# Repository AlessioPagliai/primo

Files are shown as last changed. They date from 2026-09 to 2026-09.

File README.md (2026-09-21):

# primo 

Open source humanoid robot. 3D printed structure, 30 RobStride quasi-direct-drive actuators, NVIDIA Jetson AGX Thor, Unitree G1 kinematics as reference. Still in design, not built yet: shared now so it can be built together.

[CAD on Onshape](https://cad.onshape.com/documents/2a6d830c153f862229ff478f/w/82c50406ffe66995476ba0a1/e/6ac57dbaf03b523effa40409) · [BOM](bom/bom.xlsx) · [Electrical scheme](electrical/scheme.md) · [Printable STL](cad/stl/) · [URDF](sim/urdf/primo.urdf) · [Simulation](sim/) · [Design notes](docs/) · [River Family](https://riverfamily.art/)

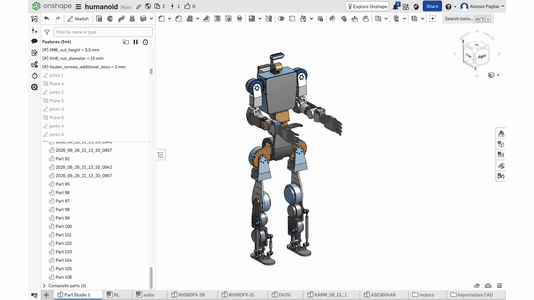
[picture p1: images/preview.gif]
primo, CAD tour and walking in Isaac Lab (https://youtu.be/6nTcHpFmKbQ)


[▶ Video in 4K](https://youtu.be/6nTcHpFmKbQ) · [Download the whole folder](https://storage.googleapis.com/riverfamily/primo/primo.zip) · [Start here to continue the project, also with an AI](AGENTS.md)

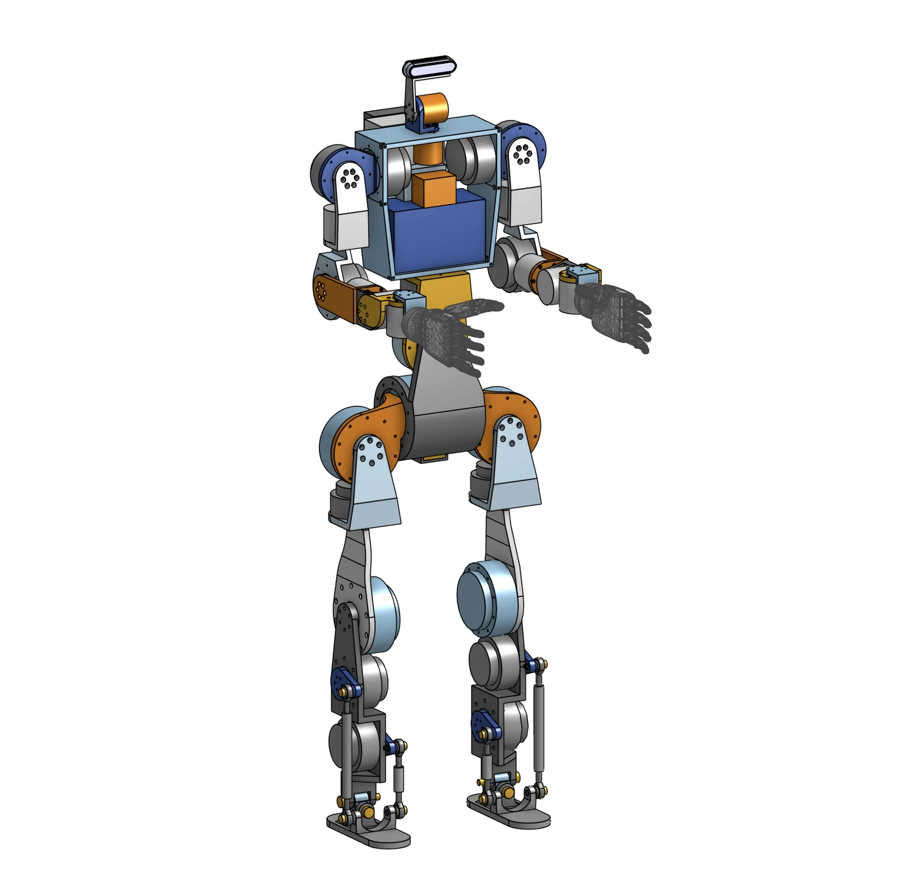
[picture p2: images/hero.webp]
primo


## Numbers

- height ≈ 1.40 m, purchased mass 33 kg, finished estimate ≈ 45 kg
- 30 DoF: legs 6 + 6, arms 7 + 7, waist 2, neck 2
- ankle: two motors in the shin, two pushrods, offset gimbal — pitch is the sum, roll the difference
- actuators, all RobStride QDD: RS04 ×6 hips and knees, RS03 ×3 waist roll and hip yaw¹, RS06 ×11 ankles, waist yaw, shoulders, elbows, RS00 ×8 shoulder yaw and wrists, RS05 ×2 neck
- power: 48 V 13S2P Li-ion 421 Wh, 24 V rail for computer and hands, hardware e-stop with precharge
- compute: Jetson AGX Thor, 5 CAN buses at 1 Mbps, RealSense D436, pelvis IMU
- hands: Inspire RH56DFX, an own 15-DoF hand is in development ([docs/hand-design.md](docs/hand-design.md))
- structure: PA-CF / PPA-CF, Bambu Lab H2C, 0.4 nozzle
- cost: ≈ EUR 30 000 all new; ≈ EUR 10 300 if Thor and hands are already owned

¹ hip yaw: the CAD currently mounts RS06, the BOM RS03. Decided by simulation before ordering the legs.

## Build order

| Phase | Content | EUR incl. VAT |
|---|---|---:|
| 1 | right arm, right hand, one ankle kit, battery, safety chain, torso on a table | 4 009 |
| 2 | legs and locomotion | 3 998 |
| 3 | left arm, waist, neck, audio, mobile | 2 258 |

Filter the `Phase` column in [bom/bom.xlsx](bom/bom.xlsx). Every row has supplier, link, mass and notes. Thor and hands are counted at zero because they are owned; reference prices are in the notes.

## Files

| Folder | Content |
|---|---|
| [bom/](bom/) | `bom.xlsx` 108 active rows, `bom.csv`, `build_bom.py` generator |
| [electrical/](electrical/) | connection scheme, written and drawn |
| [cad/](cad/) | Onshape link, printable STL of the structure, first 3MF files, RobStride FeatureScript |
| [cad/bonegen/](cad/bonegen/) | generated bones: a bone is grown by topology optimisation between the screw holes of two motors, clear of everything that moves. Thigh pilot, plan for the whole robot |
| [sim/](sim/) | URDF with meshes, mirror pipeline, ankle transmission map |
| [sim/isaaclab/](sim/isaaclab/) | walking: trained policy, Isaac Lab task code, how it was reached round by round, traps, results, next steps |
| [docs/](docs/) | why RobStride and not Encos or CubeMars, actuator tables, hand design, references, AI handoffs and working memory |
| [AGENTS.md](AGENTS.md) | entry point to continue the project, for people and AI agents |

What is printed is in `cad/stl/`. What is bought — motors, hands, battery, computer, camera, pushrods, screws — is in the BOM.

## Simulation

The right side and the centre are modelled in Onshape; `sim/mirror_urdf.py` mirrors them into the full 30-joint URDF with masses, limits and collisions: [sim/urdf/primo.urdf](sim/urdf/primo.urdf).

Walking is trained in Isaac Sim 5.1 / Isaac Lab 2.3.2 with RSL-RL PPO, on rough terrain with stairs of 5–23 cm: 12 leg joints + waist roll, mean knee flexion 36°, about 87 % of a 1000-step episode survived. Everything is in [sim/isaaclab/](sim/isaaclab/): the policy `kneehard_model_2999.pt` with the exact parameters it was trained with, the task code, the diagnostic scripts, the [story round by round](sim/isaaclab/HANDOFF.md), the [traps](sim/isaaclab/LESSONS.md), the [measured results](sim/isaaclab/RESULTS.md) and the [next steps](sim/isaaclab/NEXT_STEPS.md).

It is at 2:06 of the [video](https://youtu.be/6nTcHpFmKbQ). Clips: [KneeHard, the chosen policy](https://storage.googleapis.com/riverfamily/primo/videos/walk-kneehard.mp4) · [KneeTorque](https://storage.googleapis.com/riverfamily/primo/videos/walk-kneetorque.mp4).

## Motors

All RobStride, after comparing Encos (the motors of the Asimov robot), CubeMars, Steadywin, MyActuator, ZeroErr and Dynamixel. Encos is smaller and lighter at the same torque, but its 25–36:1 reduction gives up backdrivability and force control for good, worst on the ankle, and it is sold on quotation without public CAD. The comparison and the reasons: [docs/motor-selection.md](docs/motor-selection.md), every number in [docs/actuator-tables.md](docs/actuator-tables.md). Standard modules against custom actuators whose housing is the bone, and how a later version could get there: [docs/actuator-integration.md](docs/actuator-integration.md).

## Open points

- nothing built yet: phase 1 is the first bench
- before ordering: battery shipping to Italy and BMS limits, real ankle crank geometry, hip yaw motor — measure its torque while turning in simulation, RS06 36 Nm or RS03 60 Nm ([how](sim/isaaclab/NEXT_STEPS.md))
- walking policy: no pushes, no domain randomisation and arms held still so far; not yet ready for the real robot
- ankle torque map is derived from the CAD export and still to be verified
- e-stop does not cut hand power: decide whether it should
- STL are exported from the design state, not print-validated
- the CAD femur touches the shank assembly from about 123° of knee flexion (URDF limit 165°): decide the real joint limits ([cad/bonegen/](cad/bonegen/))
- generated bones are a pilot with assumed loads: next, loads logged from the walking policy and 2 mm resolution

## Also on

[Printables](https://www.printables.com/model/1846831) · [Thingiverse](https://www.thingiverse.com/thing:7411626) · [Cults](https://cults3d.com/en/3d-model/gadget/primo-open-source-humanoid) · [MakerOnline](https://www.makeronline.com/en/model/primo%20open%20source%20humanoid/331171.html) · [YouTube](https://youtu.be/6nTcHpFmKbQ) · [riverfamily.art](https://riverfamily.art/#primo)

## Licence

[CC0 1.0](LICENSE.md). One exception: the task code in `sim/isaaclab/code/` derives from Isaac Lab and keeps its [BSD-3-Clause licence](sim/isaaclab/code/LICENSE). Vendor files are not redistributed as CAD: motor and hand STEP files, manuals and the Unitree URDF are linked from [docs/references.md](docs/references.md).

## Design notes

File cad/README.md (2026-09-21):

# CAD

Generated bones (topology optimisation between the motors' screw holes): [bonegen/](bonegen/).

Onshape, public document: [primo](https://cad.onshape.com/documents/2a6d830c153f862229ff478f/w/82c50406ffe66995476ba0a1/e/6ac57dbaf03b523effa40409) (in Onshape it is still titled "humanoid")

Only the right side and the centre are modelled. Onshape assembly mirror does not work for real components (a mirrored motor does not exist), so the left side is generated in the simulation pipeline; in CAD, reuse the same parts and mate them to the mirrored skeleton points. Joint positions come from the Unitree G1 `g1_29dof_mode_11` URDF ([sim/g1_joints_reference.csv](../sim/g1_joints_reference.csv)).

Motors are imported STEP files from the manufacturer (not included here, see [docs/references.md](../docs/references.md)). `motor_proxy.fs` is a FeatureScript that draws RobStride envelope proxies with bolt patterns.

## STL

`stl/` — the printed structure: 20 parts, 35 files, millimetres, left and right where the part is mirrored. Exported from the current CAD through the URDF pipeline, in link coordinates: orient them in the slicer. Design state, not print-validated. For STEP or a finer tessellation export from the Onshape document.

| Area | Parts |
|---|---|
| leg | `hip_pitch_to_roll`, `hip_roll_to_yaw`, `femur`, `tibia`, `ankle_crank_upper`, `ankle_crank_lower`, `ankle_gimbal`, `foot` |
| torso | `pelvis`, `waist_roll_to_yaw`, `ribcage`, `neck_yaw_to_pitch`, `head` |
| arm | `shoulder_pitch_to_roll`, `shoulder_roll_to_yaw`, `elbow`, `elbow_pitch_to_forearm_roll`, `forearm_roll_to_pitch`, `forearm_pitch_to_yaw`, `wrist` |

Bought, not printed: motors, hands, battery, computer, camera, converters, pushrods, rod ends, screws. They are in the [BOM](../bom/bom.xlsx); their meshes exist only in [sim/meshes](../sim/meshes/) for the simulation.

## 3MF

First printed parts, Bambu Studio projects, settings inside the files.

| File | Part | Print |
|---|---|---|
| [ankle-gimbal.3mf](3mf/ankle-gimbal.3mf) | foot–shin offset gimbal, two Ø8 shoulder-screw axes stacked in Z, pitch above roll | Bambu PPA-CF, H2C, 0.4 nozzle, 0.2 mm, 1 wall, 90 % grid infill |
| [leg-test-plate.3mf](3mf/leg-test-plate.3mf) | femur, hip roll-to-yaw bracket, tibia — fit test | PLA, H2S, 0.4 nozzle, 60 % infill |

More parts follow as the design is frozen.

## Ankle

Two RS06 in the shin, one 47 mm crank each, two pushrods with igus rod ends onto the foot. Both motors move both axes: pitch = sum, roll = difference. Pins: shoulder screws Ø8 × M6, 45 mm for the gimbal axes, 16 mm for the rod-end pivots.

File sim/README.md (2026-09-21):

# Simulation

## URDF

`urdf/primo.urdf` — 30 joints, masses, limits, RobStride torque limits, first collision bodies, 32 kg. `meshes/` — 233 STL in metres, every part including the bought ones, used by the URDF. Import into Isaac Sim with *merge fixed joints* on, floating base, self-collision off.

To rebuild it after a CAD change: export the right side + centre from Onshape (URDF exporter, `rl/urdf/rl.urdf` + `rl/meshes/`), then

```bash
python3 mirror_urdf.py ~/Downloads/rl ~/Downloads/rl_full
```

The script identifies the 17 exported joints by position, renames them (`right_hip_pitch_joint` …), converts them to revolute with limits and torque limits, mirrors leg and arm into the left side, bakes mirrored STL meshes (`*_mirror.stl`), injects the real masses (motors, battery, Thor, electronics are recognised by name) and adds collision bodies. Verified symmetric to 0.000 mm. The raw export used for the current URDF is in `onshape_export/rl.urdf`; its meshes are the files in `meshes/` without `_mirror`. What is verified and what is provisional: [docs/handoffs/mirror-debug.md](../docs/handoffs/mirror-debug.md).

## Ankle transmission

`ankle_map.py` — exact inverse/forward kinematics of the pushrod differential, Jacobian, coupled torque envelope. The simulator uses two virtual joints (pitch, roll); this map converts them to the two motor angles at deploy time. Geometry constants are provisional, see [ankle-transmission.md](ankle-transmission.md).

## Isaac Lab

[isaaclab/](isaaclab/) is the whole locomotion work: the trained policy `policy/kneehard_model_2999.pt` with the parameters it was trained with, the Isaac Lab task package (rewards, terminations, action spaces, every recipe tried), the RobStride articulation with gains and limits, left-right symmetry augmentation for a biped, the diagnostic scripts, and the written record — `HANDOFF.md` round by round, `LESSONS.md` symptom → cause → fix, `RESULTS.md`, `NEXT_STEPS.md`, `setup/INSTALL.md` with the version pins. Start from [isaaclab/README.md](isaaclab/README.md): it also says which paths to edit and how `rl_full.urdf` maps to `urdf/primo.urdf`.

Earlier notes for the import, gains and acceptance tests: [docs/handoffs/isaac.md](../docs/handoffs/isaac.md). Legs run the RL policy; arms, hands and neck are teleoperated ([docs/handoffs/teleop.md](../docs/handoffs/teleop.md)).

Walking on rough terrain: [video at 2:06](https://youtu.be/6nTcHpFmKbQ) · [walk-kneehard.mp4](https://storage.googleapis.com/riverfamily/primo/videos/walk-kneehard.mp4) · [walk-kneetorque.mp4](https://storage.googleapis.com/riverfamily/primo/videos/walk-kneetorque.mp4)

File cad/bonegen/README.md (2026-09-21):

# bonegen — generated bones for primo

Handoff for the AI session on the simulation workstation. Goal set by the user: **all the bones of the robot generated, and the robot walking in Isaac Lab with them**, with the loads taken from the simulation, not assumed.

Idea: the motors stay where the CAD puts them. A bone is whatever connects the screw holes of two motors without touching anything that moves. It is generated by topology optimisation from: the motors, their screw holes, the volumes swept by the neighbours over the joint range, the screw head and tool paths, and the loads. Change a motor → change one entry → regenerate.

Mounting is the standard one for every motor (user decision): **one bone on the body holes (outer), the other bone on the output holes (inner), both on the output face.** No back mounting.

## Files

| File | What it is |
|---|---|
| `bonegen.py` | the pipeline, one file: voxelise → pads / keep-outs / screw paths → SIMP optimisation with several load cases → smooth mesh of the same volume → exact pads, holes, counterbores and motors cut with booleans → `report.json` |
| `thigh_free.json` | pilot, **free mode**: no CAD bone as input, only motors + holes + keep-outs + loads |
| `thigh.json` | same bone in CAD-interface mode (copies the attachment zones from the CAD femur). Used only to measure the current femur as baseline. Not the way forward: the copied zones ate 97 of the 187 cm³ |
| `render.py` | small renderer for comparison pictures, no GPU needed |
| `results/` | the 4 mm pilot: generated thigh (`final.stl`, millimetres, robot root frame), `report.json`, `thigh_compare.png` |

Meshes: the configs read the robot STL (metres, root frame, zero pose) from `sim/meshes` of the repository (`mesh_dir`). Known defect of the pilot mesh: a few needle-like sliver triangles from the smoothing; clean them before printing.

Setup: `python -m venv .venv`, `pip install numpy scipy pyamg scikit-image trimesh manifold3d`.
Run: `python bonegen.py thigh_free.json --pitch 4 --iters 70`; `--remesh` redoes check and meshes from a saved density; `--find-holes motor.stl y@-120:-112` lists the round holes of a mesh inside a slab.

## Config in short

- `envelope_mm` box where material may exist; `volume_cm3` mass budget (187.2 = current femur, solid PA-CF as the URDF assumes).
- `interfaces` of type `pads`: `axis`, `face` (coordinate of the motor's mounting face), `side` (which way the bone grows), `holes` (centres in the two other axes), `pad_d`, `pad_t`, `hole_d`, `head_d`, `head_depth` (counterbore), `access_len` (straight tool path kept empty), optional `ring` joining the pads. Pads are solid, holes / counterbores / tool paths are empty, both exact in the final mesh.
- `keepout_static` bodies that move with the bone. `sweeps` bodies that turn past it: swept over `range` (or `use_range`) in 3° steps, grown by `clearance_mm`. The report says if a pad lies inside a swept volume (`interface_inside_swept_volume_mm3`).
- `load_cases` wrenches at `load_centre` spread on the load pads; the other interface is fixed. Objective = sum of compliance / compliance of the current bone, so every case counts the same.

## Motor screw patterns found so far (from the meshes — check against the RobStride drawings)

| Motor | Pattern | Found |
|---|---|---|
| RS06 | output (rotor) | 6 × M4 on Ø24, on the output face |
| RS04 | body | 10 × Ø4 on Ø106.6, through the lobes; mounting face 3.6 mm behind the rotor face |
| RS04 | output (rotor) | 6 × Ø5 on Ø36 |

To do: the same for RS00, RS03, RS05 and the body pattern of RS06, in one `motors.json`, so that a bone config only says "output of motor A, body of motor B".

## What the pilot showed (Mac, 4 mm, ASSUMED loads — indicative only)

- The current CAD femur is a flat 10 mm plate. The knee of the CAD: femur plate y −129.4…−139.4 on the body holes, shank plate from −141.5 on a Ø50 hub through the femur ring. Gap 2.1 mm: **screw heads of the femur must be counterbored** or they hit the shank. Done in `thigh_free.json` (M4, 4.5 mm deep).
- Range of motion: **the current CAD femur touches the shank assembly from about 123° of knee flexion**; the URDF limit is 165° (inherited from the reference robot). The pilot keeps 0–120° free. The walking policy uses −5…116°. The real limits must be decided joint by joint.
- Free mode, same mass, forces on the leg line (y = −127), stiffness of the generated thigh against the CAD femur: lateral bending ×1.75, torsion ×1.47, knee-motor torque ×0.92, fore-aft ×0.95, axial ×0.59 (in absolute terms 0.14 → 0.24 mm under twice the body weight). In words: the flat plate is already efficient in its own plane and weak sideways and in twist; the generated shape trades a little of the first for a lot of the second. Overall a draw at this resolution. Picture: `thigh_compare.png` (current left, generated right; neighbours in blue, motors in grey, bone seen from above on the right of each group).
- At 4 mm the surface is lumpy and thin members are unreliable. Real results need 2 mm.

## Plan for the full robot

1. **Loads from the simulation.** Play the walking policy (`Isaac-Velocity-R5-KneeHard-Play-v0`; `knee_probe.py` shows how to patch `play.py`). For every joint log per step the 6D wrench the joint transmits (`robot.root_physx_view.get_link_incoming_joint_force()`, check frame and sign once with a static pose where the answer is known: robot hanging, then standing) and `robot.data.applied_torque`. Include turning, stairs, stops, and a few pushes. Per bone build 6–10 load cases: the step where each force and moment component peaks (use the 99.5th percentile, contact spikes are partly solver artefacts), plus a fall/impact case and the static worst cases. Confidence: good for walking loads, poor for impacts — keep a safety factor and say so.
2. **Bones to generate** (printed parts that are pure connections): hip pitch→roll bracket, hip roll→yaw bracket, femur, tibia (two ankle motors and pushrods inside: many keep-outs), upper arm, forearm, shoulder brackets. Keep from CAD for now: pelvis, torso, foot, ankle gimbal and cranks.
3. **Neighbours.** A bone's keep-out is the swept volume of its neighbours. Round 1 uses the CAD neighbours. Round 2 regenerates each bone against the generated neighbours. Then a clash check of every pair over the joint ranges (same `swept()` lookup) before anything goes to the simulator.
4. **Resolution.** 2–2.5 mm. CPU (scipy + pyamg) works but takes hours per bone. Faster: replace `Grid.solve` by a matrix-free conjugate gradient on the GPU (PyTorch float64: gather `u[edof]`, multiply by `KE * E_e`, `index_add_` back, Jacobi preconditioner, warm start). Nothing else changes.
5. **Back into Isaac Lab.** Mass, centre of mass and inertia of each generated bone (trimesh, density 1.25 g/cm³) → into the URDF in place of the CAD values, generated STL as visual meshes (left side by mirroring) → `convert_urdf.py --merge-joints` → fine-tune KneeHard → record the video → log the loads again → one more round of bones if they changed much. Isaac Lab cannot optimise bones while walking (links are rigid, there is no stress inside them): the loop runs in rounds.
6. **Then lighter.** Once stiffness is matched with real loads, run `--vol 0.8` and `0.7`.
7. **Printing.** FDM PA-CF is weak between layers: minimum member ≥ 5 mm, print orientation with the main load paths in the layers, or MJF/SLS for these parts. Material data from printed coupons before any safety factor is claimed.

## Rules

Never present an assumed load or modulus as measured. Interfaces exactly as the motors require. English only, assistants are called "AI".

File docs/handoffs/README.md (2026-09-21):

# AI handoffs

The design is developed together with AI agents. These files let an agent — or a person — continue the work without redoing it. Entry point: [AGENTS.md](../../AGENTS.md).

- [ai-memory.md](ai-memory.md) — the raw working memory, source of truth for every decision, with dates, sources and open doubts. Newest blocks are at the top; older sections below are marked when superseded. Read this first.
- [isaac.md](isaac.md) — importing the URDF into Isaac Sim / Isaac Lab, gains, acceptance tests, hip-yaw motor gate.
- [../../sim/isaaclab/](../../sim/isaaclab/) — the locomotion training handoff, kept with its code and policy: `HANDOFF.md` (the journey round by round), `LESSONS.md` (traps), `RESULTS.md`, `NEXT_STEPS.md`, and in `reference/` the raw work log of the simulation workstation.
- [teleop.md](teleop.md) — Meta Quest teleoperation of arms and hands, legs on the RL policy.
- [mirror-debug.md](mirror-debug.md) — what is verified in the URDF mirror pipeline and what is provisional.
- [../motor-selection.md](../motor-selection.md) — why RobStride: the comparison with Encos (Asimov), CubeMars and the others, distilled from the memory.

Rule kept throughout: no hypothesis becomes a BOM row; unknown dimensions stay `qty 0` with the missing data listed.

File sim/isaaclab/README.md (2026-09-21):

# Humanoid Locomotion — RL Training Handoff

Reinforcement-learning locomotion for an open-hardware 30-DOF humanoid (all-RobStride QDD
actuators, Unitree G1 as the geometric reference), trained in **NVIDIA Isaac Sim 5.1 / Isaac Lab
2.3.2** with **RSL-RL PPO**.

This folder contains the trained walking policy, every config needed to reproduce it, the
diagnostic tooling built along the way, and — most importantly — **a written record of what went
wrong and why**, so the next person does not repeat five rounds of mistakes.

## In this repository

The robot is called **primo**. This folder is the training package as it left the simulation workstation. Added here: this section and `code/LICENSE`; in `reference/` the assistants are called "AI".

- **URDF** — `rl_full.urdf` in these documents is [sim/urdf/primo.urdf](../urdf/primo.urdf), meshes in [sim/meshes/](../meshes/). Same export, robot name changed to `primo`. Checked: the foot mesh here has the extents the foot-collision script expects (sole at z = −0.7883 m, centre x 0.0333, y ∓0.1267).
- **USD** — not included, it is built from the URDF: foot-collision fix, then `convert_urdf.py --merge-joints` ([setup/INSTALL.md](setup/INSTALL.md)). `primo.urdf` still has the mesh collision on the feet, so run `simplify_foot_collision.py` on a copy first.
- **Paths** — written on a Windows workstation, the files point to `C:\Users\WKS\...`. Edit before running:

| File | What to change |
|---|---|
| `code/assets/robstride.py` | `ROBSTRIDE_USD_PATH` → your converted USD |
| `code/assets/project_humanoid.py` | asset folder |
| `code/scripts/simplify_foot_collision.py`, `audit_collisions.py`, `foot_zero_check.py`, `solve_elbow_angle.py` | `URDF` (and `MESHES`) → `sim/urdf/primo.urdf`, `sim/meshes/` |
| `code/scripts/preview_pose.py`, `joint_jog.py` | `USD_PATH`, `OUT_DIR` |
| `code/scripts/knee_probe.py` | `PLAY` and the `sys.path` line → your Isaac Lab checkout |
| `code/scripts/*.ps1` | venv, Isaac Lab and log folders |

`policy/params_as_trained/env.yaml` keeps the original paths on purpose: it is the record of the run.

- **Policy input and output** — read from the checkpoint and from `env.yaml`:
  - observation 272 = base linear velocity 3 · base angular velocity 3 · projected gravity 3 · velocity command 3 · joint positions relative to default 30 · joint velocities 30 · last action 13 · height scan 187 (1.6 × 1.0 m grid, 0.1 m)
  - action 13 = hip yaw, roll, pitch, knee, ankle pitch, ankle roll ×2 + waist roll. Joint position targets = default pose + 0.5 × action
  - 50 Hz control (physics 0.005 s × decimation 4), actor MLP 512-256-128 ELU, no observation normalisation
  - commands trained: forward 0–1.0 m/s, no lateral, yaw ±1.0 rad/s through a heading command
  - the joint order is the one Isaac Lab resolves from the articulation (`preserve_order: false`), not the order of the list above: read it from the running environment before any deploy
  - the ankle outputs are the two virtual joints (pitch, roll): on the robot they go through [sim/ankle_map.py](../ankle_map.py) to the two motors
- **Licence** — `code/assets/`, `code/symmetry/` and `code/tasks/` derive from Isaac Lab and keep its BSD-3-Clause licence ([code/LICENSE](code/LICENSE)). Everything else, scripts, documents and the policy, is CC0 like the rest of the repository.
- **Where it continues** — open items in [NEXT_STEPS.md](NEXT_STEPS.md). The first one, the hip-yaw torque gate, decides RS03 or RS06 on hip yaw and blocks the leg order.

## What is here

| Path | What it is |
|---|---|
| `policy/` | The chosen policy (`kneehard_model_2999.pt`), a video of it walking, and the exact env/agent YAML it trained with |
| `code/tasks/` | Isaac Lab task definitions: rewards, terminations, action spaces, every recipe tried |
| `code/assets/` | Robot articulation config — PD gains, effort/velocity limits from the real RobStride motors |
| `code/symmetry/` | Left-right symmetry augmentation for a biped (Isaac Lab ships this only for quadrupeds) |
| `code/scripts/` | Diagnostic tools: knee probe, collision audit, pose preview, symmetry verifier, launchers |
| `setup/INSTALL.md` | Environment, exact versions, the two version pins that are not optional, run command |
| `HANDOFF.md` | **The full story** — the journey round by round, what failed and why |
| `LESSONS.md` | **The traps** — distilled, each with symptom → cause → fix |
| `RESULTS.md` | Measured numbers for every experiment |
| `NEXT_STEPS.md` | What to do next (push robustness, unlocking joints, the motor gate) with the traps mapped |
| `reference/` | Raw project memory and the URDF-side handoff, kept as written |

## The policy

`policy/kneehard_model_2999.pt` — 3000 PPO iterations, rough terrain with stairs.

- Action space: 12 leg joints + waist roll (13 DOF). Arms/wrists/neck are PD-held.
- Measured gait: mean knee flexion **36.1°**, range −5°…116°, nearly-straight only **0.4 %** of the time.
- Survives ~87 % of a 1000-step episode on generated rough terrain including 5–23 cm stairs.
- Left-right symmetric (symmetry augmentation active during training).

## Reproduce

See `setup/INSTALL.md`, then:

```bash
# train
isaaclab.bat -p scripts/reinforcement_learning/rsl_rl/train.py \
    --task Isaac-Velocity-R5-KneeHard-v0 --num_envs 1024 --headless

# watch a trained policy
isaaclab.bat -p scripts/reinforcement_learning/rsl_rl/play.py \
    --task Isaac-Velocity-R5-KneeHard-Play-v0 --num_envs 4 \
    --checkpoint /abs/path/to/kneehard_model_2999.pt

# measure whether the knees actually bend (don't trust your eyes)
isaaclab.bat -p code/scripts/knee_probe.py \
    --task Isaac-Velocity-R5-KneeHard-Play-v0 --checkpoint /abs/path/model.pt --headless
```

## Status and next steps

Working: stable symmetric walking on rough terrain and stairs, bent knees, soft landings,
arms held along the body.

Not yet done:
1. **Hip-yaw torque gate** — log applied torque on `*_hip_yaw_joint` during turning. If it
   saturates the 36 Nm RS06 limit for >2–5 % of steps, the BOM's RS03 (60 Nm) is required.
   **This measurement blocks the Phase-1 motor purchase.**
2. Push/disturbance robustness (no push randomisation has ever been enabled).
3. Unlocking more joints (arm swing, waist yaw) for a more natural gait.
4. Domain randomisation (mass, friction, latency) before any sim-to-real attempt.
5. A separate conservative "walk mode" for precise positioning — see `HANDOFF.md` round 3 for
   how *not* to do it.

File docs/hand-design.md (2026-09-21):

# Custom Humanoid Hand Design

Shared engineering handoff for the user and the AI sessions.

Last updated: 2026-07-29

## Project Status

The humanoid will initially use the commercial Inspire Robots
`RH56DFX-2L` and `RH56DFX-2R` hands already represented in CAD and the BOM.
They remain the first-build baseline.

In parallel, the project will develop and open-source its own five-finger
hand. This is a planned project workstream, not merely a component comparison.
The custom hand is intended to replace the Inspire hands after validation.

Do not remove the Inspire hands from the active BOM until the custom hand has
passed force, backlash, heating, impact, lifetime, communication, and
integration tests.

## Intended Kinematics

Target: 15 independently actuated DoF per hand, three per digit.

| Digit | DoF 1 | DoF 2 | DoF 3 |
|---|---|---|---|
| Index, middle, ring, little | MCP abduction/adduction | MCP flexion/extension | PIP flexion/extension |
| Thumb | CMC opposition/reposition | CMC or MCP flexion/extension | IP flexion/extension |

The thumb must not blindly copy the four-finger axis arrangement. Opposition
is required for useful pinch grasps.

The DIP joints can initially be mechanically coupled to their corresponding
PIP joints or left passive. This preserves three controlled DoF per digit
without adding a fourth actuator.

The preferred architecture places an actuator physically at each controlled
joint. Tendon actuation remains the fallback if no sufficiently compact,
controllable, and reproducible commercial actuator is available.

## Packaging Reality

The DYNAMIXEL X330 envelope is `20 x 34 x 26 mm`. Although compact for a smart
servo, it is large for a human-scale PIP joint:

- A bare 20 mm motor thickness becomes approximately 24-28 mm after adding
  structural cheeks and an opposite-side support.
- The 34 mm body consumes most of a phalanx length.
- Adjacent fingers can collide during abduction.
- A motor mounted at the PIP increases distal inertia.
- Connectors and moving cable loops require additional clearance.

Therefore, XL330/XC330 actuators are suitable in a palm or forearm and possibly
at selected MCP joints, but are poor candidates for every direct PIP joint.

## Actuator Comparison

Torque values must distinguish sustainable/rated operation from momentary
stall torque.

| Actuator | Size | Mass | Rated or conservative torque | Stall or maximum torque | Control and feedback | Status |
|---|---:|---:|---:|---:|---|---|
| Waveshare `SC09` / Feetech `SCS009` | 23.2 x 12.0 x 25.5 mm | 12.5 g | 0.0686 Nm | 0.2256 Nm | TTL bus; position, estimated load, speed, voltage | Leading retail direct-joint prototype candidate |
| DYNAMIXEL `XL330-M288-T` | 20 x 34 x 26 mm | 18 g | about 0.104 Nm | 0.52 Nm | Absolute magnetic encoder, current control, current/temperature feedback, TTL | Technically better, but bulky on fingers |
| DYNAMIXEL `XC330-T288-T` | 20 x 34 x 26 mm | 23 g | about 0.20 Nm | 1.00 Nm | Absolute encoder, current control, metal gears, TTL | Strong and durable but bulky and expensive |
| KST `X06` | 20 x 7 x 16.6 mm | 6 g | 0.040 Nm | 0.176 Nm | PWM; no normal runtime telemetry | Fits easily but weak and poor for state logging |
| AGFRC `A20CLS` | 23 x 12 x 27.5 mm | 20 g | not published | 0.735 Nm advertised at 8.4 V | PWM, potentiometer, no normal runtime current telemetry | Compact and strong, but weak research interface |
| Harmonic Drive `RSF-3C` | approximately diameter 20 x 47 mm | 31 g | 0.03-0.11 Nm | 0.13-0.30 Nm, ratio-dependent | Incremental encoder; external servo driver required | Robot-grade but long, expensive, quotation-oriented |
| Bonsystems `BCSA Micro` | diameter 18 mm; other dimensions unpublished | unpublished | unpublished | unpublished | Unpublished | Promising dedicated finger actuator, not BOM-ready |

### Product Links

- SC09 product and CAD: <https://www.waveshare.com/SC09-Servo.htm>
- SC09 documentation: <https://www.waveshare.com/wiki/SC09_Servo>
- XL330-M288-T European supplier:
  <https://www.generationrobots.com/it/403817-servomotore-dynamixel-xl330-m288-t.html>
- XL330 official manual and CAD:
  <https://emanual.robotis.com/docs/en/dxl/x/xl330-m288/>
- XC330-T288-T European supplier:
  <https://www.generationrobots.com/it/403891-servomotore-dynamixel-xc330-t288-t.html>
- XC330 official documentation:
  <https://emanual.robotis.com/docs/en/dxl/x/xc330-m288/>
- KST X06 European supplier:
  <https://openelab.io/it/products/kst-x06-v6-hv-servo>
- AGFRC A20CLS manufacturer:
  <https://www.agfrc.com/index.php?id=2429>
- AGFRC A20CLS European supplier:
  <https://www.monsterhopups.de/Servo-AGF-RC-A20CLS>
- Harmonic Drive RSF-Supermini:
  <https://staging.harmonicdrive.net/products/actuators-and-motors/solid-shaft-actuators/rsf-supermini>
- Bonsystems BCSA Micro:
  <https://en.bonsystems.com/media-center/product-video/micro-actuator-bcsa-micro-series-promotion-viedo/>

## SC09 Versus XL330 Torque

The XL330 is not merely a more expensive SC09. It is stronger and provides
substantially better sensing and control:

- Conservative normal torque ratio:
  `0.104 / 0.0686 = 1.52`.
- Stall torque ratio:
  `0.52 / 0.2256 = 2.30`.
- XL330 encoder resolution: 4096 positions over 360 degrees, 0.088 degrees.
- SC09 sensor resolution: 1024 positions over 300 degrees, 0.293 degrees.
- XL330 supports measured-current control and current-limited position control.
- SC09 reports an estimated load value, not calibrated joint torque.

The SC09 advantage is packaging and cost:

- Thickness: 12 mm instead of 20 mm.
- Bounding volume: approximately 7.1 cubic centimetres instead of 17.7.
- Mass: 12.5 g instead of 18 g.
- Retail price: approximately USD 8.99 instead of about EUR 40.20.

## Approximate Fingertip Force

First-order estimate:

`fingertip force = joint torque / distance from joint to contact`

This ignores changing contact geometry, transmission losses, compliance, and
multi-joint load sharing.

| Joint and assumed lever | SC09 rated | SC09 stall | XL330 conservative | XL330 stall |
|---|---:|---:|---:|---:|
| MCP, 70 mm | 0.98 N | 3.22 N | 1.49 N | 7.43 N |
| PIP, 30 mm | 2.29 N | 7.52 N | 3.47 N | 17.33 N |

Stall force is momentary. It must never be used as sustainable grasp force.

The SC09 is dimensionally plausible for a direct-joint hand, but its
approximately 1 N rated MCP fingertip force makes it a light-manipulation
candidate. A complete grasp is also limited by the thumb opposition joint and
the available fingertip friction.

## Complete-Hand Implications

### Fifteen SC09 Actuators

- Actuator mass: approximately 187.5 g per hand.
- Motor purchase cost: approximately USD 135 per hand before shipping/tax.
- Theoretical simultaneous stall current: 15 A at 6 V.
- One shared TTL bus is possible, with adequate parallel power distribution.
- Suitable for a compact first prototype and light manipulation.
- Not yet proven adequate for useful box lifting or tool operation.

### Fifteen XL330 Actuators

- Actuator mass: 270 g per hand.
- Motor purchase cost: approximately EUR 603 per hand.
- Theoretical simultaneous stall current: about 22.1 A at 5 V.
- Better torque, state feedback, current limiting, SDK, and ROS support.
- Poor direct-PIP packaging.
- Better suited to protected palm/forearm tendon actuation.

### Mixed XL330 and SC09

A possible architecture would use XL330 motors at MCP flexion and SC09 motors
at MCP abduction and PIP flexion. This improves proximal torque while keeping
the fingers thinner.

However:

- The two products use different serial protocols.
- They require separate UART/protocol handling even if both use a common
  approximately 5 V power rail.
- The mechanical and control behaviour would be inconsistent across joints.

This remains an option, not a selected design.

## Mechanical Requirements

Every direct rotary joint should include:

- A motor-driven side and a coaxial passive support on the opposite side.
- A fork or double-shear structure rather than a long cantilever from the
  servo horn.
- Mechanical end stops before software or internal servo limits.
- Replaceable joint modules and accessible fasteners.
- Cable strain relief and a controlled flex loop at each moving joint.
- Finger pads with known friction and some passive compliance.
- Clearance for adjacent fingers throughout abduction and full flexion.
- A protected cable route that cannot enter pinch points.

The final CAD should model the complete actuator, horn, opposite support,
fasteners, connectors, cable bend radius, and service clearance. Comparing
only bare motor bodies is insufficient.

## Sensing And Learning Requirements

For teleoperation, ACT policies, and simulation-to-real work, record at least:

- Commanded joint position.
- Measured joint position.
- Joint velocity.
- Motor current or the best available load estimate.
- Bus voltage.
- Temperature when available.
- Command and feedback timestamps.

The SC09 does not provide measured current or temperature. Its load value must
be characterized experimentally and must not be treated as calibrated torque.
External fingertip tactile sensors or force-sensitive resistors may eventually
be required for controlled grasping.

## Validation Plan

Do not purchase 30 custom-hand actuators before validating one finger.

### Prototype 1

Build one index finger with:

- MCP abduction/adduction.
- MCP flexion.
- PIP flexion.
- A passive or coupled DIP.
- The intended structural material, bearings/supports, cables, and fingertip
  pad.

SC09 is the current first actuator to test because it is inexpensive and
dimensionally plausible. This is a test choice, not the final hand lock.

### Measurements

1. Sustained fingertip force for at least 60 seconds.
2. Peak force without using prolonged stall.
3. Loaded position error.
4. Backlash and deadband in both directions.
5. Temperature over repeated grasp cycles.
6. Impact survival with conservative test loads.
7. Wear after repeated cycles.
8. Bus update rate with three nodes, then fifteen nodes.
9. Simultaneous current draw during realistic grasps.
10. Ability to identify joint state accurately enough for teleoperation and
    policy training.

### Selection Gate

Freeze the actuator and hand CAD only after the prototype demonstrates:

- Sufficient sustainable force for the intended objects.
- Acceptable backlash and repeatability.
- No thermal failure in repeated use.
- Adequate impact durability.
- Reliable multi-node communication.
- A realistic power and wiring architecture.

If SC09 fails force or sensing requirements, compare a stronger direct module,
a mixed MCP/PIP design, or a palm-mounted tendon architecture. Do not solve a
failed actuator test by designing around advertised stall torque.

## Current Decision Summary

- Inspire RH56DFX remains the first humanoid hand.
- A custom open-source 15-DoF hand will be developed in parallel.
- Direct joint actuation is preferred.
- XL330/XC330 are too bulky for every human-scale PIP joint.
- SC09 is the leading low-cost direct-joint prototype candidate, but it is
  weaker and less observable than XL330.
- No custom-hand actuator is procurement-locked.
- The immediate next step is one instrumented three-DoF finger prototype.

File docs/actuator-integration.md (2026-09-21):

# Standard motors, or the housing as the bone

primo uses standard actuator modules: a closed cylinder with a bolt circle on the body and a bolt circle on the rotating output face. The best commercial humanoids use custom actuators whose housing is the structural link itself. This page records what that difference costs, what stays valid in the future, and how a later version of the robot could move towards integrated housings. Market statements are general knowledge on 2026-09-21, not a verified survey.

## Two families

| | Standard module (RobStride, CubeMars, Encos, cobot joints) | Custom integrated (Unitree, Tesla, Figure) |
|---|---|---|
| Interface | bolt circle on the body, bolt circle on the output face | the link is the housing, or clamps around it |
| Who can build it | anyone, parts can be ordered | only the maker |
| Torque per mass | RS04 ≈ 84 Nm/kg | Unitree custom ≈ 189 Nm/kg |
| Housing | dead mass, carried inside a bone | structure, heat sink and cable duct at once |
| Robot | primo ≈ 45 kg | G1 ≈ 35 kg |

Both families will keep existing. Robot arms built from standard joint modules bolted to simple links have been an industry for fifteen years; humanoids on standard modules already walk (Asimov on Encos, ToddlerBot on Dynamixel, primo in simulation). The number of module makers grows and prices fall. The penalty of the standard route is mass and bulk at the joints, not the ability to walk. For an open source robot standard modules are the point: a custom housing cannot be rebuilt by others.

## What is future proof and what is not

- Not future proof: bones drawn around the exact shape of one motor.
- Future proof: the motor as a swappable box with a declared interface — axis, envelope, body holes, output holes — and bones regenerated from that description. This is what [cad/bonegen/](../cad/bonegen/) does. A better module (lighter, hollow shaft, clampable) then costs one entry in the motor list and a new run.
- Mounting rule kept for every motor: one bone on the body holes (outer), the other bone on the output holes (inner), both on the output face. The consequence is measured in the CAD knee: the thigh is a ring plate on the 10 body holes, the shank reaches the 6 output holes through a Ø50 hub in the middle of that ring, so the shank stands off by the thickness of the thigh plate (10 mm + 2 mm gap) and the thigh screws must be counterbored.
- Clamping a bone around the motor body, as on the G1, suits aluminium links: clamp and heat sink in one. With printed PA-CF it insulates the motor (rated torque is a thermal limit: RS04 120 Nm peak, 40 Nm rated), creeps under preload, and RobStride housings are not specified for radial clamping. Face screws with metal inserts remain the right joint for a printed robot.

## The integrated route, if a later version takes it

What can be bought is a frameless motor kit: two bare rings, the stator (iron stack with the windings) and the rotor (ring with the magnets). Catalogue items from several makers. Nobody makes the stator or the rotor themselves. Everything else is made or sourced:

- housing: holds the stator by press or bonded fit and is its heat path, so aluminium
- rotor hub, rotor bearings, and an output bearing that carries the joint moments (crossed roller or a thin-section pair)
- gearbox, the hard part. Low reduction: a single-stage planetary in hardened steel from a gear shop. Berkeley Humanoid Lite prints a cycloidal stage in plastic. High reduction: a harmonic component set, three parts made to be built into a custom housing
- two encoders (rotor and output), magnet ring and sensor chip
- driver board with field-oriented control and CAN
- assembly: retaining compound, fits of a few hundredths, a jig to insert the rotor against the pull of the magnets

A complete low-reduction actuator with gearbox, encoders, driver and hollow shaft, sold without housing so that only the housing is printed, is not a catalogue item as far as known. There is a mechanical reason: in a planetary actuator the housing is part of the gearbox, it carries the ring gear and the bearing seats. The closest things are harmonic servo kits made for integration (high reduction and expensive: rejected for the legs in [motor-selection.md](motor-selection.md)), housed modules with a hollow shaft, and asking a module maker for an OEM variant with a custom housing.

Metal printing the housing: services print AlSi10Mg, but as printed it is rough and accurate to about ±0.1–0.2 mm. Stator bore, bearing seats and gear seat are finish-machined afterwards in any case. A plain round housing is cheaper and more precise turned from bar. Printing pays when the housing is also the bone: organic shape printed near net, functional seats machined in one setup.

RobStride and CubeMars are this recipe sold as a product, descended from the MIT Mini Cheetah actuator. At about EUR 200 per actuator it cannot be beaten on cost; the gain would be integration only, against months of development per actuator size, with gear quality and heat as the main risks.

## Suggested path

1. This version on standard modules, bones generated by [cad/bonegen/](../cad/bonegen/).
2. A cheap step available at once: metal bones (machined or printed aluminium) on the hottest joints with the same motors, for stiffness and a real heat path.
3. Later, as a separate experiment on one joint (knee): frameless kit, planetary stage, open driver, on a bench against an RS04 — torque, heat, backlash. Because every bone is generated from a motor interface, the robot can adopt such an actuator joint by joint.

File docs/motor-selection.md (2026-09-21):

# Motor selection

primo uses 30 RobStride quasi-direct-drive actuators. That was decided on 2026-06-20/21, after an all-Encos plan (the route of the Asimov robot) and a CubeMars plan had each been adopted and dropped. This page is the short version. Every number is in [actuator-tables.md](actuator-tables.md); the dated record, with the mistakes, is in [handoffs/ai-memory.md](handoffs/ai-memory.md).

## What was asked of a motor

- low reduction, backdrivable (QDD, 6–10:1): current ≈ torque, stiffness that can be dosed from the controller, tolerance to impacts. It is what Unitree G1 does, and RL walking on it needs no torque sensor
- driver inside, CAN, two encoders (single-encoder versions such as RS01 are excluded, whatever the brand)
- orderable by anyone, with public dimensions and CAD, at a price a university or a maker can pay
- one family from 5 to 120 Nm: one firmware, one debug tool, one set of spares
- compared at equal torque: size and mass first, then cost, then availability

## Timeline

| Date | Step |
|---|---|
| 2026-06-14 | brands compared at equal torque. RobStride is the baseline BOM |
| 2026-06-16 | Asimov v1 taken as reference (same parallel ankle). Its Encos motor map rebuilt joint by joint, Encos quote asked to Foxtech |
| 2026-06-17 | reduction ratio studied for walking: 6–9:1 is the QDD range, reflected inertia grows with the square of the ratio |
| 2026-06-19 | all-Encos list finalised: A6416 ×6 legs, A4315 ×16 mid joints, A2806 ×8 wrists and neck, A4310 ×4 ankle trial |
| 2026-06-20 | reverted: QDD architecture, RobStride supplier, Unitree G1 as the reference. A CubeMars plan made just before is dropped, it rested on wrong dimensions |
| 2026-06-21 | CubeMars AK45-36 (36:1, slim) evaluated for arms and ankles and rejected: all QDD, no high reduction anywhere. Map locked: RS04 ×6, RS03 ×3, RS06 ×11, RS00 ×8, RS05 ×2, 20.9 kg of actuators. Accepted cost: ≈ 45 kg and ≈ 1.40 m instead of 35 kg and 1.20 m |
| 2026-06-23 | RobStride against CubeMars class by class: no switch |

## Asimov and Encos

[Asimov v1](https://github.com/asimovinc/asimov-1) is the closest open robot: 1.2 m, 35 kg, 25 DoF, the same two-motor parallel ankle. It uses Encos actuators on every joint, five models ([their documentation](https://docs.menlo.ai/asimov/1)):

| Encos model | Gearbox | Qty | Joints on Asimov |
|---|---|---:|---|
| EC-A4310-P2-36 | planetary 36:1 | 10 | ankles ×4, elbows ×2, wrist yaw ×2, neck ×2 |
| EC-A4315-P2-36 | planetary 36:1 | 4 | knees ×2, shoulder roll ×2 |
| EC-A6416-P2-25 | planetary 25:1 | 3 | hip pitch ×2, waist yaw |
| EC-A5013-H17-100 | harmonic 100:1 | 4 | hip roll ×2, shoulder pitch ×2 |
| EC-A3814-H14-107 | harmonic 107:1 | 4 | hip yaw ×2, shoulder yaw ×2 |

The map comes from their leg BOM and spreadsheet, the arm joints matched through the `armature` values of their simulation model. Encos is Nanjing Inks Intelligent Technology, resold by Foxtech and AIFITLAB. About USD 7 000 for the 25 actuators.

What Encos does better, and it is not small:

| 36 Nm class | Size | Mass | Nm/kg | Reduction | Price |
|---|---|---:|---:|---|---|
| Encos EC-A4310-P2-36 | Ø56 × 60.5 | 382 g | 94 | 36:1 | ≈ USD 500–700 |
| RobStride RS06 | Ø88 × 49 | 621 g | 58 | 9:1 | ≈ EUR 200 |

On the legs EC-A6416 is Ø88 and 805 g against Ø106 and 1 420 g of RS04, same 120 Nm peak: −3.7 kg on six joints. Stiff and precise in position, which is good for calm walking and for position-based manipulation policies (ACT, diffusion).

Why it was not chosen:

- reduction. Reflected inertia against RobStride 9:1 is about 8× at 25:1 and 16× at 36:1, 100× and more on the harmonic joints. The joint is less backdrivable, answers worse to impacts, and current stops being a usable measure of torque. The worst place is the ankle, the contact joint, exactly where Asimov has 36:1
- it cannot be fixed later. High reduction walks well when every actuator has an output torque sensor (the Tesla route). Encos planetary has none and is too stiff to estimate torque from its two encoders. A QDD keeps force control, compliance and contact-rich manipulation open by software; 36:1 closes them in hardware
- reproducibility. Encos is sold on quotation by resellers, without public CAD or dimensions. Foxtech answered quickly, but price to Italy, CAD and lead time were still open when the decision was taken. RobStride has public specifications and STEP, and is in stock at Seeed Studio and several other shops
- price: about 3.5× at 36 Nm; the 150 Nm Encos A10020 is ≈ USD 2 250 against ≈ USD 255 of RS04
- the target moved. Asimov fitted a light, tethered robot that walks calmly on flat floor. primo carries its battery, weighs ≈ 45 kg and is meant for rough terrain, pushes and later dynamic motion: the Unitree G1 class, which is QDD

Honest note: for calm walking plus position-based manipulation only, Encos was judged the better fit (2026-06-20). RobStride was chosen for what the robot should be able to become. The price is paid in size and mass: Ø88 ankles and arms, a longer shin, about 2.5 kg more between ankles and arms.

## CubeMars

Same family of actuator as RobStride (low-reduction QDD, MIT Mini Cheetah lineage; T-Motor is the same company). A first CubeMars plan rested on reading the model name as the diameter: AK70-9 is Ø89 × 49, not Ø70; AKE90-8 is Ø107.5 × 43.5, not Ø90. With the real sizes:

| Class, joints | RobStride | CubeMars | Verdict |
|---|---|---|---|
| ≈ 5 Nm, neck | RS05 Ø46 × 44, 191 g, 5.5 / 1.6 Nm | AK40-10 Ø53 × 37, 185 g, 4.1 / 1.3 Nm | RS05: smaller and stronger |
| 10–15 Nm, wrists, shoulder yaw | RS00 Ø57 × 51, 310 g, 14 / 5 Nm | AKE60-8 Ø69 × 25, 260 g, 12.5 / 5 Nm · AK45-10 Ø53 × 43, 260 g, 7 / 2.5 Nm | RS00. AKE60-8 only if thickness is the problem |
| 25–36 Nm, ankles, shoulders, elbows | RS06 Ø88 × 49, 621 g, 36 / 11 Nm | AK70-9 Ø89 × 49, 540 g, 29 / 8.5 Nm · AKE80-8 Ø87 × 32, 570 g, 30 / 12 Nm | no CubeMars win: same size and weaker, or thinner with external driver |
| 50–60 Nm, hip yaw, waist roll | RS03 Ø98 × 54, 900 g, 60 / 20 Nm | AK10-9 Ø98 × 62, 940 g, 53 / 18 Nm | RS03 |
| 120–170 Nm, hip pitch and roll, knee | RS04 Ø106 face, ≈ Ø120 envelope × 56, 1 420 g, 120 / 40 Nm | AKE90-8 Ø107.5 × 43.5, 1 400 g, 170 / 55 Nm | the only real CubeMars upgrade |

Torque is peak / rated. CubeMars has nothing compact around 36 Nm, where primo has most of its joints, and its AKE motors need an external driver; RobStride has the driver inside and no gap from RS05 to RS04. CubeMars costs about twice (AKE90-8 ≈ USD 484 plus driver against ≈ USD 255). It was not dropped for control reasons: it was dropped to keep one ecosystem, together with Damiao.

Still open as an upgrade: AKE90-8 on hips and knees, +50 Nm and 13 mm thinner at the same mass, if the simulated leg torques ask for it. The slim 36:1 AK45-36 (Ø55 × 54, 24 / 8 Nm) was rejected for the same reason as Encos.

## Others

| Candidate | Type | Outcome |
|---|---|---|
| Dynamixel PH42, PH54 | cycloidal position servo, 300–500:1 | wrong class: not backdrivable, 29–33 rpm, PH54 USD 3 541 and still 44 Nm. ToddlerBot walks on small Dynamixel servos, at 3.4 kg |
| ZeroErr eRob | harmonic, torque sensor, brake and driver inside | from Ø70 and 0.77 kg, 60 rpm: too big for the ankle, slow for the knee, expensive |
| Honpine, Leaderdrive, Laifual | harmonic with torque sensor option | same category as ZeroErr, quotes asked, not pursued |
| HEBI X-series | series elastic | premium, low torque density |
| Steadywin GIM3510, GIM6010-36 | small planetary, MIT protocol, public CAD | candidate for wrists in the Encos plan. Not needed with RS00 |
| MyActuator RMD-X | planetary | best ROS 2 support and CAD, bigger per Nm |
| Damiao DM-J4310 | QDD | cheap, removed with CubeMars to keep one ecosystem |
| RobStride RS01 | QDD, one encoder | excluded |
| RobStride RS02 | QDD, 17 / 6 Nm | reserve at quantity 0 |

## Open

- standard modules or housing as the bone, and what keeps the design future proof: [actuator-integration.md](actuator-integration.md)
- hip yaw: RS03 in the BOM, RS06 in the CAD. Decided by the torque measured in simulation: [sim/isaaclab/NEXT_STEPS.md](../sim/isaaclab/NEXT_STEPS.md)
- check simulated torques against the rated figures, not the peak ones: RS04 is 120 Nm peak and 40 Nm rated
- leg upgrade to AKE90-8 only if those torques ask for it

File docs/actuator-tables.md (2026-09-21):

# MOTOR SPEC TABLES — primo (scannable master reference)

> Quick-look spec tables for every motor we researched. The short rationale is in [motor-selection.md](motor-selection.md), the dated record in [handoffs/ai-memory.md](handoffs/ai-memory.md).
> Datasheet-confirmed numbers are exact; `~` = estimate. Backlash units matter: planetary in **arcmin (')**, harmonic in **arcsec (")** — harmonic has ~60× less backlash.
> **Status: the robot is all RobStride (section 4), decided 2026-06-20/21. Sections 1 and 3b record earlier choices and are superseded.**
> Data last updated 2026-06-21; status labels corrected 2026-09-21.

---

## 1. SUPERSEDED 2026-06-20 — all-Encos list of 2026-06-19, 3 sizes + ankle trial (34 on the quote list = 30 in robot + 4 trial)

| Model | Ø mod | Weight | Peak Nm | Cont Nm | Ratio | Cont/Peak RPM | Qty | Joints |
|---|---|---|---|---|---|---|---|---|
| EC-A6416-P2-25 | Ø88 | 805 g | 120 | 40 | 25:1 | 107/120 | 6 | legs: hip pitch/roll, knee |
| EC-A4315-P2-36 | Ø56 | 485 g | 75 | 25 | 36:1 | 109/117 | 16 | ankle×4, shoulder×6, elbow×2, hip-yaw×2, waist×2 |
| EC-A2806-P2-36 | Ø44 | 162 g | 12 | 3 | 36:1 | 207/220 | 8 | wrist×6 + neck×2 |
| EC-A4310-P2-36 | Ø56 | 382 g | 36 | 12 | 36:1 | 75/89 | 4 | ankle TRIAL spares |

---

## 2. ENCOS — full PLANETARY lineup (datasheet V3.15EAP)

| Model | Ratio | Ø mod | Length | Weight | Cont Nm | Peak Nm | Cont/Peak RPM | Kt (Nm/A) | Backlash | Nm/kg | Foxtech $ |
|---|---|---|---|---|---|---|---|---|---|---|---|
| EC-A2806-P2-36 | 36:1 | Ø44 | 44 | 162 g | 3 | 12 | 207/220 | 1.35 | 12' | 74 | ~320 (est) |
| EC-A4310-P2-36 | 36:1 | Ø56 | 60.5 | 382 g | 12 | 36 | 75/89* | 1.4 | 10' | 94 | 500 |
| EC-A4315-P2-36 | 36:1 | Ø56 | 69.5 | 485 g | 25 | 75 | 109/117 | 2.8 | 10' | **155** | 520 |
| EC-A6408-P2-25 | 25:1 | Ø88 | 59.5 | 604 g | ~20 | 60 | — | — | — | — | — |
| EC-A6416-P2-25 | 25:1 | Ø88 | 67.5 | 805 g | 40 | 120 | 107/120 | 2.74 | 15' | 149 | 650 |
| EC-A8112-P1-18 | 18:1 | ~Ø81 | ~ | ~830 g | ~ | ~94 | — | — | — | — | — |
| EC-A10020-P2-24 | 24:1 | ~Ø100 | ~ | ~1350 g | ~85 | ~127 | ~57 | — | — | — | — |

*A4310 measured at 24 V → at 48 V speed ~1.5–2×. All: dual encoder, CAN/CAN-FD 1 Mbps, cross-roller bearing.

---

## 3. ENCOS — full HARMONIC lineup (datasheet V3.15EAP) — **all have dual encoder; flexspline → deflection torque sensing VIABLE**

| Model | Ratio | Ø mod | Length | Weight | Cont Nm | Peak Nm | Cont/Peak RPM | Kt (Nm/A) | Backlash | Nm/kg | Foxtech $ |
|---|---|---|---|---|---|---|---|---|---|---|---|
| EC-A3814-H14-107 | 107:1 | Ø53 | 78.5 | 434 g | 20 | 60 | 47/52 | 4.2 | **10"** | 138 | 680 |
| EC-A5013-H17-100 | 100:1 | Ø63 | 81.5 | 630 g | 30 | 90 | 33/38 | 5.9 | **10"** | 143 | 780 |
| EC-A6013-H20-100 | 100:1 | Ø73 | 84 | 906 g | 40 | 130 | 45/47 | 5.6 | **10"** | 143 | — |

**Harmonic note:** backlash ~10 **arcsec** (vs ~10 arcmin planetary → 60× tighter) and the compliant flexspline winds up measurably, so the dual encoder CAN estimate torque from deflection (like ZeroErr) — the planetary models can't. BUT it's SLOW (33–52 RPM, like ZeroErr) and Encos doesn't ship a turnkey torque function (you'd DIY the deflection→torque, marginal with their 0.1–0.2° encoder accuracy).

---

## 3b. CUBEMARS — QDD + high-reduction in ONE ecosystem (MIT-mode, dual-encoder) — evaluated, NOT chosen (briefly the chosen supplier before 2026-06-20, on wrong dimensions)

| Model | Ratio | Peak Nm | Rated Nm | Size | Weight | Backdrivable | Our use |
|---|---|---|---|---|---|---|---|
| ~~AK40-10~~ | 10:1 | 4.1 | ~1.5 | ~~Ø46~~ | ~~200 g~~ | ✅ QDD | WRONG SIZE, kept for the record. Real data in the last row |
| AK45-10 | 10:1 | 7 | ~2 | Ø53×43 | 260 g | ✅ QDD | wrist |
| ~~AK70-9 V3.0~~ | 9:1 | 29 | 8.5 | ~~Ø70~~ | ~~~720 g~~ | ✅ QDD | WRONG SIZE, the model name was read as the diameter: this error produced the CubeMars choice. Real data two rows below |
| AK80-9 V3.0 | 9:1 | 22 | 9 | Ø80 | 485 g | ✅ QDD | (light mid) |
| AK10-9 V3.0 | 9:1 | 53 | 18 | Ø98×61.7 | 940 g | ✅ QDD | ankle pitch, hip yaw, waist |
| AK70-9 V3.0 | 9:1 | 29 | 8.5 | **Ø89×49** | 540 g | ✅ QDD | ankle roll, shoulder, elbow (NB: Ø89 = same as RS06 Ø88, NOT Ø70!) |
| **AKE90-8** | 8:1 | **170** | 55 | **Ø107.5×43.5** (1.4 kg, 121 Nm/kg) | 1.4 kg | ✅ QDD | **LEGS: hip pitch/roll, knee** (NB: Ø107.5 ~ same as RS04, NOT Ø90) |
| AKH70-16 | 16:1 | 85 | 26 | Ø70 hollow | — | ⚠️ semi | (compact-strong alt) |
| AK45-36 | 36:1 | 24 | 8 | **Ø55×54** | 340 g | ❌ stiff | EVAL+REJECTED: slim (Ø55) but 36:1 closes futureproofing (force/compliance/dynamics), WORST on the ankle (contact joint). See note. |
| AK80-64 | 64:1 | 120 | 48 | **Ø98×61.9** | 850 g | ❌ stiff | NOT smaller than RS04 (Ø98 vs Ø110); stiff -> useless on the legs |
| AK40-10 | 10:1 | 4.1 | 1.3 | **Ø53×37** | 185 g | ✅ QDD | neck (but RS05 Ø46 is smaller) |

**DECISION 2026-06-21 (CubeMars reopening closed): EVERYTHING STAYS QDD, no 36:1.** The user reopened the question for the AK45-36 36:1 (Ø55 vs RS06 Ø88 = slimmer arms/ankle). HONEST VERDICT after 3 questions from the user: (1) QDD is more FUTUREPROOF - 36:1 closes FOREVER force/impedance control + compliance + impact tolerance on that joint (a hardware life sentence, not upgradeable in software). (2) 36:1 is WORST on the ANKLE (contact joint, wants compliance the most) -> keep the ankle QDD. (3) On the ARMS 36:1 is fine ONLY for TODAY's position-based manipulation (ACT/diffusion), but it kills future contact-rich/compliant manipulation. Since the user cares about futureproofing/smart control -> **ALL QDD, AK45-36 REJECTED**. Chunky arms/ankle (Ø88) = cosmetic price + ~2.5 kg, does NOT limit capability; 36:1 does. The RobStride map locked earlier STAYS valid (or CubeMars-QDD AKE90 for stronger legs, 170 vs 120 Nm). NB: the AI had over-sold the AK45-36 in the previous turn, the user rightly corrected it.

CubeMars (T-Motor / Sanrui, 17 yr, IPO 2026) spans QDD->high-reduction -> pick backdrivable where it matters. More mature than RobStride. ~~Slimmer leg actuator (AKE90 Ø90 vs RS04 Ø110)~~ — correction: AKE90-8 is Ø107.5, the same diameter class as RS04; it is thinner (43.5 vs 56 mm) and stronger (170 vs 120 Nm), not slimmer.

## 4. ROBSTRIDE — **CHOSEN** — QDD (~9:1, MIT-Cheetah lineage, torque from current, NO sensor)

Specific torque is calculated on the complete actuator as `output torque / actuator mass`. The `>10 Nm/kg` target is
normally quoted using peak torque, but rated specific torque is also shown because it is the more conservative thermal check.

| Model | Ø mm | Ratio | Peak Nm | Rated Nm | Mass kg | Peak Nm/kg | Rated Nm/kg | Peak >10 | Rated >10 | Length mm | Encoder | Price ~ | Current use / note |
|---|---:|---:|---:|---:|---:|---:|---:|---|---|---:|---|---:|---|
| RobStride 05 | Ø46 | 7.75:1 | 5.5 | 1.6 | 0.191 | **28.8** | **8.4** | PASS | **FAIL** | — | dual | ~$110 | neck only; not a major load-bearing joint |
| RobStride 00 | Ø57 | 10:1 | 14 | 5 | 0.310 | **45.2** | **16.1** | PASS | PASS | 51 | dual | ~$125 | shoulder yaw x2 + wrists x6 = 8 selected |
| RobStride 02 | Ø78 | 7.75:1 | 17 | 6 | 0.380 | **44.7** | **15.8** | PASS | PASS | 45.5 | dual | ~$145 | reserve, not currently selected |
| RobStride 06 | Ø88 | 9:1 | 36 | 11 | 0.621 | **58.0** | **17.7** | PASS | PASS | 49 | dual | ~$210 | ankles x4 + waist yaw x1 + shoulder pitch/roll x4 + elbows x2 = **11** selected |
| **RobStride 03** | **Ø106** | **9:1** | **60** | **20** | **0.900** | **66.7** | **22.2** | **PASS** | **PASS** | **56** | **dual** | **~$225** | waist roll x1 + **hip yaw x2** = **3** selected (hip yaw upgraded from RS06 2026-06-21: 45 kg aggressive turn ~36 Nm = RS06 limit -> RS03 60 Nm headroom) |
| RobStride 04 | Ø110 | 9:1 | 120 | 40 | 1.420 | **84.5** | **28.2** | PASS | PASS | 50 | dual | ~$255 | hip pitch/roll + knees, 6 total |

Source for mass, rated torque and peak torque: [RobStride Product Specification 2025-06-26](https://files.seeedstudio.com/products/RobStride/%E7%81%B5%E8%B6%B3%E6%97%B6%E4%BB%A3%E4%BA%A7%E5%93%81%E8%A7%84%E6%A0%BC%E4%BB%8B%E7%BB%8D%20RobStride%20Product%20S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).
Retail links: [RS00](https://www.seeedstudio.com/Robostride-00-Actuator-p-6664.html), [RS02](https://www.seeedstudio.com/Robostride-02-Actuator-p-6665.html), [RS03](https://www.seeedstudio.com/Robostride-03-Actuator-p-6774.html), [RS04](https://www.seeedstudio.com/Robostride-04-Actuator-p-6775.html), [RS05](https://www.seeedstudio.com/Robostride-05-Actuator-p-6666.html), [RS06](https://www.seeedstudio.com/Robostride-06-Actuator-p-6668.html).

Also: RS01 (**single encoder — avoid**). All QDD ~8–10:1, dual encoder, CAN 1M, 48V, FOC — backdrivable, torque from current out-of-box, NO instrumentation. Bigger per Nm than Encos.
**Map updated 2026-06-21 (30 actuators, ≈ 20.913 kg):** RS04 x6 hip pitch/roll+knees; **RS03 x3 waist-roll + hip-yaw x2**; **RS06 x11** ankles/waist-yaw/shoulder-pitch-roll/elbows; RS00 x8 shoulder-yaw+wrists; RS05 x2 neck. (Was: RS03 x1 + RS06 x13 / 20.355 kg; hip yaw moved RS06->RS03, +0.558 kg.) Waist pitch is deleted; hip pitch supplies sagittal torso motion. Ankle = **DIFFERENTIAL** (2 RS06 in shin, 2 push-rods to one foot shaft, sum=pitch / diff=roll; pitch uses both motors -> ~72 Nm, covers 45 kg push-off without leverage).

---

## 5. ALTERNATIVES EVALUATED (reference / rejected)

| Brand / model | Type | Ø | Peak Nm | Weight | Max RPM | Torque sensing | Verdict |
|---|---|---|---|---|---|---|---|
| **ZeroErr eRob 70F** | harmonic | Ø70 | 35 | 0.77 kg | 60 | **integrated (sensor + dual-enc + brake + driver)** | smallest I-series; ankle pick (tight push-off) |
| ZeroErr eRob 70I | Ø70 | Ø70 | 70 | 0.88 kg | 60 | integrated | mid/ankle-strong |
| ZeroErr eRob 80F | harmonic | Ø80 | 71 | 0.89 kg | 60 | integrated | knee/hip light |
| ZeroErr eRob 80I | harmonic | Ø80 | 112 | 1.09 kg | 60 | integrated | knee/hip (the "strong" pick) |
| ZeroErr eRob 90I | harmonic | Ø90 | 191 | 1.64 kg | 60 | integrated | heavy |
| ZeroErr eRob 110I | harmonic | Ø110 | 408 | 2.68 kg | 60 | integrated | — |
| ZeroErr eRob 142I/170I | harmonic | Ø142/170 | 892/1180 | 6.7/9.5 kg | 40 | integrated | industrial |
| ZeroErr eRob T-series | harmonic | +3–8 | same | heavier | 60 | integrated | RIGHT-ANGLE (corner) variants |
| Honpine / Leaderdrive / Laifual | harmonic | varies | varies | — | — | integrated torque-sensor option | ZeroErr PEERS, cheaper (CN); Leaderdrive=RobotEra supplier |
| HEBI X-series | SEA | — | — | — | — | series-elastic torque fb | US, best API, premium, lower torque density |
| Innfos/DAMIAO SCA | QDD | — | — | — | — | torque sensing | lighter (QDD) alternative |
| CubeMars AK10-9 | QDD | Ø98 | ~50 | 940 g | fast | current only | gap at 36 Nm; ecosystem |
| CubeMars AK70-10 | QDD | Ø89 | 25 | — | fast | current only | — |
| CubeMars AK40-10 | QDD | Ø53 | 4 | 185 g | fast | current only | — |
| Steadywin GIM3510-8 | QDD | Ø46 | 6.3 | — | — | dual-enc | wrist option |
| Steadywin GIM6010-36 | planet | Ø70 | 36 | — | slow | dual-enc | mid, 36:1 stiff |
| Dynamixel PH54/PH42 | cycloidal >300:1 | — | ~25–44 | 340 g+ | 29–33 | position servo | wrong class (not backdrivable, costly) |
| Damiao DM-J4310 | QDD | — | ~10 | — | fast | dual-enc | cheap ($116), single-ecosystem |

**ZeroErr rejected for legs:** min Ø70 / 0.77 kg (too big for ankle) + **60 RPM max** (too slow for dynamic). Confirmed from official eRob page.

---

## 6. TORQUE-SENSING OPTIONS (since Encos planetary = stiff, can't self-sense)

| Approach | How | Mass / size | Cost | Difficulty | Notes |
|---|---|---|---|---|---|
| **Sensorless UKF estimate** | Fuse motor current + encoders + IMU + **foot GRF** in an observer (IIT ergoCub, open-source) | ~zero added | low (sw) | medium (friction ID + tuning) | **Best fit** — avoids per-joint sensors. RMSE 0.05–2.5 Nm. Friction model is for harmonic → re-ID for planetary. |
| Strain-gauge flange | 4 gauges ±45° full bridge on a designed spoke/tube | ~zero | low ($) | high (bonding, thermal) | lightest, no compliance; craft-heavy |
| Dual mag-encoder flexure | 2 magnetic encoders across a torsion spring | tens of g | low ($) | medium | becomes a stiff SEA; easy electronics |
| Magnetoelastic (non-contact) | magnetize shaft, read field | small | buy (NCTE) | very high DIY | stiff, non-contact; = Tesla |
| Harmonic w/ deflection | use Encos-H / ZeroErr flexspline windup | in-actuator | motor cost | turnkey (ZeroErr) | needs harmonic, slow |
| Foot GRF (chosen for feet) | 4 load cells at foot corners, or strain gauges on the sole plate | ~zero (gauges) | ~€50 (gauges) / cheap | low–med | gives Fz + CoP/ZMP (the wrench the estimator needs). **Bota REJECTED** (cost+distal weight). |
| ~~Ready-made 6-axis F/T (Bota)~~ | ~~Rokubi/PixONE/MiniONE~~ | ~~30–500 g~~ | ~~$1–3k ea~~ | none | REJECTED 2026-06-19: too costly + distal weight. |

---

## Legend
- **Cont Nm** = continuous/rated (thermal-limited); **Peak Nm** = short-duration max.
- **Ø mod** = real module outer diameter (NOT the stator Ø in the Encos name).
- Encos name = EC-A[stator Ø][stator height]-[P planetary / H harmonic][stages]-[REDUCTION].
- All Encos (planetary AND harmonic) = dual encoder + CAN/CAN-FD; planetary can't self-sense torque (too stiff), harmonic can (flexspline).

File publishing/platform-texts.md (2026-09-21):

# Publishing texts

Same short text everywhere, no marketing, no AI labels. Commits and uploads are authored only as Alessio Pagliai: no co-author lines. Name: `primo` (lowercase on the site and on MakerOnline, `Primo` elsewhere).

## Published 2026-09-19

- GitHub https://github.com/AlessioPagliai/primo
- YouTube https://youtu.be/6nTcHpFmKbQ (4K60, H.264, closed GOP; an HEVC open-GOP upload looped on YouTube and was deleted)
- riverfamily.art https://riverfamily.art/#primo — more = video, make = primo.zip
- Printables https://www.printables.com/model/1846831
- Thingiverse https://www.thingiverse.com/thing:7411626
- Cults https://cults3d.com/en/3d-model/gadget/primo-open-source-humanoid
- Creality Cloud https://www.crealitycloud.com/it/model-detail/6aae7192f052c066aeb8dd96 — listing complete (CC0, 20 tags, 37 files, docs) but rejected by moderation: the cover must be a real photo of the print. Creality has no drafts: the rejected listing stays private and editable, which serves as the draft. Edit it from the profile (3D model › ⋯ › Edit), add the photo as cover, set the name to "Primo open source humanoid robot", resubmit. Not linked publicly until approved
- MakerOnline https://www.makeronline.com/en/model/primo%20open%20source%20humanoid/331171.html
- MakerWorld https://makerworld.com/it/@RiverFamily — draft complete (title, Robotica, 13 tags, covers 4:3 and 3:4, 4 images, STL pack as raw files, ankle-gimbal print profile, CC0) rejected once by the automatic check (no real photo), now kept as a draft (3D models › Drafts, draft 9688828). From its Edit page add a photo of a printed part to the model images and to the print profile, drag `primo-30s.mp4` into the model video slot (it refuses scripted uploads), publish
- Whole folder https://storage.googleapis.com/riverfamily/primo/primo.zip · STL pack https://storage.googleapis.com/riverfamily/primo/primo-stl.zip
- Videos https://storage.googleapis.com/riverfamily/primo/videos/ (primo-4k60.mp4, primo-30s.mp4, walk-*.mp4) · site video https://storage.googleapis.com/riverfamily/videos/Primo_720p.mp4

## Title

`Primo open source humanoid robot`

## One line

Open source humanoid, 3D printed, 30 RobStride actuators, Jetson Thor. In design.

## Description

Primo is an open source humanoid. 3D printed structure in PA-CF, 30 RobStride quasi-direct-drive actuators, NVIDIA Jetson AGX Thor, Unitree G1 kinematics as reference. Height ≈ 1.40 m, ≈ 45 kg.

Video, CAD tour and walking in Isaac Lab: https://youtu.be/6nTcHpFmKbQ

Still in design, not built yet. Everything is shared to build it together: CAD, printable STL of the structure, bill of materials with links, electrical scheme, URDF, simulation files, walking policies in Isaac Lab and the handoff to continue the project, also with an AI.

Files here: the printed structure as STL (20 parts, left and right, millimetres, design state) and the first print projects as 3MF, the ankle offset gimbal and a leg test plate (femur, hip bracket, tibia). What is bought, motors, hands, battery, computer, screws, is in the bill of materials.

CAD: https://cad.onshape.com/documents/2a6d830c153f862229ff478f/w/82c50406ffe66995476ba0a1/e/6ac57dbaf03b523effa40409
Everything else: https://github.com/AlessioPagliai/primo
Whole folder: https://storage.googleapis.com/riverfamily/primo/primo.zip

Print: PA-CF or PPA-CF, 0.4 nozzle, Bambu Lab H2C. Ankle gimbal 3MF: Bambu PPA-CF, 0.2 mm, 1 wall, 90 % grid infill. Leg test plate 3MF: PLA on an H2S, fit test only.

Licence: CC0, public domain.

## Tags

humanoid, humanoid robot, robot, robotics, open source, open hardware, biped, walking robot, 3d printed robot, diy robot, android, actuator, robstride, jetson, nvidia, isaac sim, reinforcement learning, unitree g1, onshape, urdf

Extra where there is room: quasi direct drive, jetson thor, isaac lab, mechatronics, engineering, pa-cf, ppa-cf, river family, primo

## YouTube chapters

0:00 Overview · 0:36 Ankle · 0:58 Arm, hand and hip · 1:14 Poses · 1:42 Inside the torso · 2:06 Walking in Isaac Lab

## Images

`publishing/images/` — hero, pose, ankle, cad-page, each white-padded to 4:3, 16:9 and 1:1. Cults wants 1:1, YouTube 16:9, the others 4:3 (MakerWorld and Creality also take a 3:4 app cover).

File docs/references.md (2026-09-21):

# References

## Vendor documents (not redistributed)

- RobStride actuators RS00 / RS03 / RS04 / RS05 / RS06 — manuals, CAD and specification: [robstride.com](https://www.robstride.com/), retail and STEP on [Seeed Studio](https://www.seeedstudio.com/Robostride-04-Actuator-p-6775.html) and [AIFITLAB](https://aifitlab.com/products/robstride-04-motor)
- Inspire Robots RH56DFX hands — [product](https://en.inspire-robots.com/product/rh56dfx), [RH56 series user manual](https://en.inspire-robots.com/wp-content/uploads/2024/02/INSPIRE-ROBOTS-THE-DEXTEROUS-HAND-RH56-SERIES-USER-MANUAL.pdf)
- Unitree G1 description and URDF `g1_29dof_mode_11` — [unitree_ros](https://github.com/unitreerobotics/unitree_ros/tree/master/robots/g1_description) (BSD-3)
- NVIDIA Jetson AGX Thor developer kit — [developer.nvidia.com](https://developer.nvidia.com/embedded/jetson-agx-thor-developer-kit)
- Intel RealSense D436 — [CAD and docs](https://dev.realsenseai.com/docs/stereo-depth-camera-d400#cad-files)
- Phidgets MOT0110_0 IMU — [product](https://www.phidgets.com/?prodid=1205)
- igus igubal KARM-08 CL / KALM-08 CL rod ends — [igus](https://www.igus.eu/)
- NVIDIA Isaac Lab, base of the training code in `sim/isaaclab/code/` — [isaac-sim/IsaacLab](https://github.com/isaac-sim/IsaacLab) (BSD-3)

## Motors compared and not chosen ([motor-selection.md](motor-selection.md))

- Asimov v1, open source humanoid on Encos actuators — [asimovinc/asimov-1](https://github.com/asimovinc/asimov-1) (CAD, BOM, simulation model), [documentation](https://docs.menlo.ai/asimov/1), [BOM form](https://tally.so/r/jaG0va)
- Encos (Nanjing Inks Intelligent Technology) EC-A series, datasheet V3.15EAP on request — resellers [Foxtech](https://store.foxtech.com/), [AIFITLAB](https://aifitlab.com/)
- CubeMars AK and AKE series (same company as T-Motor) — [cubemars.com](https://www.cubemars.com/)
- Steadywin GIM series, CAD and manuals — [steadywin-motor.com](https://www.steadywin-motor.com/)
- MyActuator RMD-X — [myactuator.com](https://www.myactuator.com/), ROS 2 driver [2b-t/myactuator_rmd_ros](https://github.com/2b-t/myactuator_rmd_ros)
- ZeroErr eRob — [zeroerr.cn](https://en.zeroerr.cn/)
- ROBOTIS Dynamixel — [emanual.robotis.com](https://emanual.robotis.com/)

## Papers

- 1809.11110 — The igus Humanoid Open Platform — Allgeuer
- 1909.06586 — Highly Dynamic Quadruped Locomotion via Whole-Body Impulse Control and MPC — Kim
- 2103.04675 — Bipedal Humanoid Hardware Design: A Technology Review — Ficht
- 2104.09025 — The MIT Humanoid Robot: Design, Motion Planning, and Control for Acrobatic Behaviors — Chignoli
- 2204.03897 — Sim-to-Real Transfer of Compliant Bipedal Locomotion on Torque Sensor-Less Gear-Driven Humanoid — Masuda
- 2301.04317 — Teleoperation of Humanoid Robots: A Survey — Darvish
- 2303.04137 — Diffusion Policy — Chi
- 2304.13705 — Learning Fine-Grained Bimanual Manipulation with Low-Cost Hardware — Zhao
- 2309.13037 — GELLO — Wu
- 2310.08864 — Open X-Embodiment — Open X-Embodiment Collaboration
- 2312.07843 — Foundation Models in Robotics — Firoozi
- 2402.18380 — UKF-Based Sensor Fusion for Joint-Torque Sensorless Humanoid Robots — Sorrentino
- 2404.18201 — What Foundation Models can Bring for Robot Learning in Manipulation — Li
- 2405.17227 — Learning Generic and Dynamic Locomotion of Humanoids Across Discrete Terrains — Yu
- 2406.09414 — Depth Anything V2 — Yang
- 2406.12731 — Tactile SoftHand-A — Li
- 2409.15239 — TacPalm — Zhang
- 2410.12685 — Physics-Informed Learning for the Friction Modeling of High-Ratio Harmonic Drives — Sorrentino
- 2410.16591 — Cycloidal Quasi-Direct Drive Actuator Designs with Learning-based Torque Estimation — Zhu
- 2502.00893 — ToddlerBot — Shi
- 2503.14734 — GR00T N1 — NVIDIA
- 2504.17249 — Berkeley Humanoid Lite — Chi
- 2507.10105 — PINN with UKF for Sensorless Joint Torque Estimation in Humanoid Robots — Sorrentino
- 2508.00162 — CHILD: Whole-Body Humanoid Teleoperation System — Myers
- 2509.16469 — A Framework for Optimal Ankle Design of Humanoid Robots — Cervettini
- 2510.10206 — It Takes Two: Interactive Whole-Body Control Between Humanoid Robots — Liu
- 2511.06796 — Human-Level Actuation for Humanoids — Sunbeam

Each id resolves at `https://arxiv.org/abs/<id>`.

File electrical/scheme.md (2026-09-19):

# Electrical connection scheme — primo

Written 2026-07-17, updated 2026-07-18 (hand connection verified from the official Inspire manuals, linked in [docs/references.md](../docs/references.md)).
Matches the BOM revision with hands on the WEHO rail and the hardware precharge chain
([bom/bom.xlsx](../bom/bom.xlsx), total EUR 30,477.03 all new). Drawing: [scheme.svg](scheme.svg) · [scheme.png](scheme.png).
Negative returns are not drawn: every negative goes back to the Eaton PDU negative pole and the battery negative.
The WEHO converter is non-isolated, so the 24 V negative is the same net as the battery negative.

## 1. Power sources

| Source | Use | Connection |
|---|---|---|
| Bicycle Motor Works 13S2P Molicel P45B, 46.8 V nom / 54.6 V full, BMS 45 A cont / 100 A max | Mobile | `XT90-S` discharge lead. The XT90-S is the physical service disconnect: separate it only with the robot stopped and the LEV100 open |
| Matched 54.6 V charger (order with battery) | Charging, bench only | Separate `XT60` charge lead |
| MEAN WELL RSP-3000-48 bench supply (230 VAC in) | Bench bring-up | Feeds the same chain at the main-fuse input instead of the battery. Do not assume it absorbs regeneration |

**Dual-source mode (added 2026-07-19, MS1 requirement):** battery AND grid connected at the same
time. The two sources must NEVER be hard-paralleled — the fixed 48 V supply would float-charge the
13S pack uncontrolled, and either source can back-feed the other. They join through the
`[TO SELECT] Dual-source 48 V OR-ing stage` (one ideal-diode branch per source, common output into
the main fuse; LTC4357/LM5050 class, sized for the bench current). Until that stage is selected
and bench-verified, the safe interim procedure is source swapping at the XT90-S: battery OR grid,
never both plugged in.

## 2. 48 V distribution

```text
BATTERY + ──XT90-S──> BF1 70 A MAIN FUSE (as close to the pack as possible) ──25 mm2 trunk──> SPLIT NODE
                                                                                   │
   ┌───────────────────────────────────────────────────────────────────────────────┤
   │ UNSWITCHED compute branch (always on)                                         │ SWITCHED motor branch
   │                                                                               │
   │  MINI 15 A ──> WEHO WH-C482410 (48 V -> 24 V, 10 A, 240 W)                    ├──> CIT K2 contact ──> 100 ohm 50 W ──┐  (precharge,
   │               + >=22 uF low-ESR cap at the output (to size)                   │                                      │   in parallel
   │               = 24 V RAIL, see section 3                                      ├──> LEV100A5ANG contactor (100 A) ────┤   with LEV100)
   │                                                                               │                                      v
   │                                                                               └───────> EATON 16220-2 PDU (+ / −) <──┘
   │                                                                                          │
   │                                            ┌─────────────────┬──────────────────────────┼──────────────────┬─────────────────┐
   │                                        BF1 70 A          BF1 70 A                   BF1 40 A           BF1 30 A          BF1 30 A
   │                                        16 mm2            16 mm2                     6 mm2              6 mm2             6 mm2
   │                                        LEFT LEG          RIGHT LEG                  WAIST+NECK         LEFT ARM          RIGHT ARM
```

Motor branches (30 actuators; every branch fuse in a Littelfuse `04980921GXM5` covered holder):

| Branch | Fuse | Cable | Motors | CAN bus |
|---|---|---|---|---|
| Left leg | BF1 70 A | 16 mm² | RS04 hip pitch, RS04 hip roll, RS03 hip yaw, RS04 knee, RS06 ankle A, RS06 ankle B | Thor native CAN0 |
| Right leg | BF1 70 A | 16 mm² | same as left leg | Thor native CAN1 |
| Waist + neck | BF1 40 A | 6 mm² | RS03 waist roll, RS06 waist yaw, RS05 neck pan, RS05 neck tilt | CANable #3 |
| Left arm | BF1 30 A | 6 mm² | RS06 shoulder pitch, RS06 shoulder roll, RS00 shoulder yaw, RS06 elbow, RS00 wrist roll, RS00 wrist pitch, RS00 wrist yaw | CANable #1 |
| Right arm | BF1 30 A | 6 mm² | same as left arm | CANable #2 |

Motor power/CAN drops: RS03 and RS04 use `AMASS XT30UW-F` power plus `JST GH 1.25` CAN connectors;
RS06, RS00 and RS05 use the combined Seeed `BCCA4011` XT30 (2+2) leads (16 AWG power + 26 AWG CAN in one cable).

## 3. 24 V rail (always on, from the WEHO)

| Tap fuse (MINI, 58 VDC) | Load | Notes |
|---|---|---|
| 10 A | Thor `J74` Micro-Fit 3.0 power input | Pins 1–2 = +24 V, pins 3–4 = GND (NVIDIA pinout, verify on the kit); 2+2 contacts, 18 AWG each; Molex 43025-0400 housing + 43030 contacts; Thor nvpmodel capped at 130 W (~5.4 A) |
| 15 A | Both RH56DFX hands | 2 A max each documented; one shared fused branch routed inside the two arm trunks. OPEN DECISION: hands stay powered during e-stop unless a small 24 V relay is added in this branch |
| 2 A | Waveshare USB hub power input (7–36 V) | Hub supplies its own 5 V ports |
| 2 A | Safety-control chain (section 4) | A WEHO failure drops the chain and the motor bus: fail-safe |

Power budget (user decision 2026-07-17): Thor 130 W + hands 96 W + hub/interfaces ≈ 241 W vs 240 W rated —
over budget only at fully coincident peak, riding the 12 A over-current margin. Bench-log before locomotion.

## 4. Safety / power-up chain (pure hardware, 24 V)

```text
24 V RAIL ──MINI 2 A──> E-STOP XB4BS8442 (NC, latching, external, metal bezel) ──> node A
node A ──[START XB5AA31 (NO, momentary)] ─┬─> node B
node A ──[K1 seal-in contact] ────────────┘
node B ──> K1 latch coil (CIT A2K1CSQ24VDC1.6 #2)  [TVS 1.5KE33CA]
node B ──> K2 precharge coil (CIT A2K1CSQ24VDC1.6 #1)  [TVS 1.5KE33CA]
node B ──> H3YN-2 DC24 timer supply (ON-delay, initial 10 s, freeze at 4-5 tau measured)
timer NO contact ──> LEV100 coil  [TVS 1.5KE33CA]
```

Behavior:

1. Press START: K1 latches through its own contact, K2 closes (precharge through the 100 ohm resistor begins),
   the timer starts. The RobStride actuators boot during precharge and report VBUS over CAN: this is the free
   bus-voltage measurement used to calibrate the delay.
2. Timer expires: LEV100 closes on an already-charged bus (no arc), the resistor path is bypassed.
3. E-stop pressed (or 24 V lost): K1, K2, timer and LEV100 all drop, the motor bus is dead. Thor, hub, camera,
   IMU and audio stay alive on the unswitched rail and log the event.
4. Releasing the e-stop restarts nothing: only START does. Thor additionally refuses motor enable until VBUS
   telemetry matches battery voltage, but software is not part of the chain.

## 5. Data connections (Thor port map)

Note on "native CAN": the Thor dev kit has NO CAN connector on the I/O panel. CAN0/CAN1 come out
of the **J47 internal pin header** on the carrier board (CAN_H/CAN_L directly, transceivers
on-board per the NVIDIA docs note of 2026-07-12) through a custom crimped harness — the BOM row
`[TO DESIGN qty0] Wiring Thor J47` — whose mating connector and pinout must be verified on the
physical kit before purchase. Fallback if verification contradicts the docs: two more CANable Pro
on USB, no other change.

```text
THOR native CAN0 (J47) ──120R──[ left leg bus: 6 motors, 1 Mbps, ~45% ]──120R
THOR native CAN1 (J47) ──120R──[ right leg bus: 6 motors, 1 Mbps, ~45% ]──120R
THOR USB-A #1 ──> RealSense D436 head camera (USB 3, direct; keep off the hub)
THOR USB-A #2 ──> Waveshare USB3.2 HUB 4U (powered from 24 V)
                   ├─> MKS CANable Pro #1 ──120R──[ left arm bus: 7 motors, ~53% ]──120R
                   ├─> MKS CANable Pro #2 ──120R──[ right arm bus: 7 motors, ~53% ]──120R
                   ├─> MKS CANable Pro #3 ──120R──[ waist+neck bus: 4 motors, ~30% ]──120R
                   └─> Phidgets MOT0110 pelvis IMU (CBL4011 USB cable, 280 mm)
THOR USB-C #1 ──LINDY 36940──> Waveshare 2CH RS485 ── CH A ──> LEFT hand RS485
                                                    └─ CH B ──> RIGHT hand RS485
THOR USB-C #2 ──LINDY 41899──> Waveshare USB TO AUDIO ──PH2.0──> PUI AS03604AR speaker (mic on board)
THOR USB-C debug: recovery/flash only, keep free
```

### Hand connection detail (verified 2026-07-18 from `hands/` manuals)

Each RH56DFX has **one GX12 5-pin aviation plug** carrying both power and communication
(RH56 series user manual §1.4.1 — confirm unchanged on the delivered DFX; no DFX-specific manual is published, ask Inspire at order):

| GX12 pin | Signal | Comes from |
|---|---|---|
| 1 | GND | 24 V negative (shared 15 A hand branch, in the arm trunk) |
| 2 | VCC 24 V | 15 A hand fuse on the WEHO rail |
| 3 | RS485 A+ | Waveshare 2CH adapter, that hand's channel |
| 4 | RS485 B− | Waveshare 2CH adapter, that hand's channel |
| 5 | GND | ground reference for RS485 |

RH56DFX electrical data (2026-02 official selection guide): DC 24 V ±10%, quiescent 0.09 A, **peak 2 A**
(this officially confirms the WEHO power-budget figure), 540 g. RS485 defaults: 115200 bps, 8N1;
register protocol (0xEB 0x90 framing) or MODBUS RTU (0x03/0x06/0x10); one `HAND_ID` per hand — assign
left = 1, right = 2 (each hand is alone on its channel, but distinct IDs prevent mistakes when bench-testing
both on one bus, which the protocol supports up to 254 nodes).

CAN wiring rules: Belden `9841NH` (LSZH) shielded 120 ohm pair, bus topology with short stubs, exactly two
`YAGEO MFR-25FBF52-120R` terminations per bus (10 total). The CANable Pro adapters are STM32F072
candleLight/gs_usb, galvanically isolated; do not substitute the STM32G431 "V2.0". Set a nonzero
`CAN_TIMEOUT` on every actuator and bench-test the safe stop. The final CAN-ID / connector / termination-point
map is the `HAR-MAP-01` deliverable.

## 6. Gated before wiring (do not build from this document alone)

- Electrical-engineer release: wire gauges, connector pinouts, fuse coordination, grounding and shield
  termination, e-stop and precharge wiring (`SEQ-PWR-01` drawing), WEHO output capacitor.
- Physical verification: Thor `J74`/`J47` pinouts on the delivered kit, XT90-S gender on the delivered pack,
  RobStride GH-connector mating on a sample harness, D436 delivered outline, and the GX12 connector/pinout on
  the delivered RH56DFX hands (series-manual data; DFX-specific manual not published).
- Decisions still open: e-stop relay in the hand branch (yes/no); battery order gates (BMS trip curve, regen
  charge limit, Italy shipping).

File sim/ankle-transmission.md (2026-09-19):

# Ankle differential transmission — derived from CAD, 2026-07-19

> **Provisional geometry.** The crank/rod/pivot dimensions below were extracted from mesh centroids of the Onshape export, not from measured CAD dimensions. Ratios, torque envelope and rod-end angles are therefore indicative only, until the linkage is measured in the CAD and the constants in `ankle_map.py` are replaced.

Companion to `ankle_map.py` (the runnable model). Answers the question "do we need to
simulate the pushrods?" and records the numbers that came out of the real geometry.

## Decision: do NOT simulate the pushrods as bodies

- URDF cannot express closed kinematic loops at all; Isaac/PhysX can (loop-closure joint),
  but it costs solver stability and speed for zero benefit to the policy.
- Every mainstream humanoid RL pipeline (Unitree, MIT, Berkeley) trains on **virtual serial
  ankle joints** and applies the transmission at deploy time. This project already decided
  this (MEMORY 2026-07-12); the geometry below confirms it is a good approximation.
- What DOES have to reach the simulator is the **consequence** of the linkage: the coupled,
  configuration-dependent torque envelope. Everything else is handled by `ankle_map.py`
  outside the policy.

## Geometry (right leg, extracted from the Onshape export, all mm)

| Quantity | Value |
|---|---|
| Crank arm, both motors | 47.75 (horizontal at zero pose) |
| Rod 1 (upper motor) eye-to-eye | 208.01 (BOM body 140 + 2 rod ends) |
| Rod 2 (lower motor) eye-to-eye | 106.01 (BOM body 40 + 2 rod ends) |
| Foot pivot pitch arm | 47.75 forward of the pitch axis |
| Foot pivot lateral half-span | 43.83 (87.65 apart) |
| Rods at zero pose | vertical; cranks at 90° to them (optimal transmission) |

This settles the old BOM question: the AliExpress rod length is the **body** length;
eye-to-eye = body + ~68 mm.

## Transmission (validated: IK→FK round trip exact to machine precision)

```
pitch = -0.500  x (th1 + th2)      common mode   -> ratio 1 : 1
roll  = -0.545  x (th2 - th1)      differential  -> ratio 1.09 : 1
```

Motor travel needed for the full URDF joint range: ±43° for pitch, ±14° for roll,
worst corner (full plantarflex + full roll) th1 = +55.6°, th2 = +31.5°. Well inside RS06 range.

**The ratio is not constant** — available torque varies 46…84 Nm across the workspace
(±25%). For training that is absorbable with domain randomization, but the **deploy-time
map must be the exact nonlinear solve in `ankle_map.py`**, not the linear ratio above.

## Torque envelope (RS06 peak 36 Nm each)

At neutral: pure pitch **72.0 Nm**, pure roll **66.1 Nm**, coupled by

```
|tau_pitch| / 72 + |tau_roll| / 66  <=  1        (diamond, not a box)
```

Continuous (RS06 rated 11 Nm): pitch **22.0 Nm**, roll **20.2 Nm**.

Pitch torque vs ankle angle (roll = 0):

| ankle pitch | available pitch torque |
|---|---|
| −50° (max plantarflex) | 46.0 Nm |
| −25° | 62.6 Nm |
| −15° (typical toe-off) | 66.8 Nm |
| 0° (neutral) | 72.0 Nm |
| +30° (dorsiflex) | 84.2 Nm |

**Corrected the URDF**: ankle roll effort was 36 Nm (a guess), the derived value is 66 Nm —
it had been 1.8× too conservative. Pitch 72 Nm was correct.

## Findings that matter for the machine

1. **Push-off is exactly at the design boundary.** MEMORY estimates ~67 Nm peak plantarflexion
   demand at 45 kg; the mechanism delivers 66.8 Nm at 15° plantarflexion and less beyond.
   Comfortable at ~35–40 kg, zero margin at 45 kg. Do NOT change CAD yet — measure the real
   demand in Isaac (same philosophy as the hip-yaw gate). If it saturates, the fix is a
   **smaller crank arm** (40 mm → 86 Nm) at the cost of ankle speed and higher rod force
   (754 N now → 900 N; igus KARM-08 CL is rated 1.7 kN short-term, so it still fits).
2. **Continuous torque limits the standing posture.** 22 Nm continuous means the standing CoM
   must sit within ~50 mm of the ankle axis (45 kg × 9.81 × 0.05 = 22 Nm). Standing with the
   CoM 90 mm forward would need 40 Nm — fine as a peak, thermally not fine as a pose. Add a
   reward/posture term that keeps the CoP near mid-foot.
3. **Rod ends are comfortably within spec — the old worry is retired.** Worst per-end
   misalignment across the whole workspace is **15.7°** (at full roll) against the igus
   KARM/KALM-08 CL **35°** limit. Pitch costs ~0° (rotation about the pin axis). The earlier
   plan to restrict roll to ±12°, and the conical-spacer / ball-stud upgrade paths, are not
   needed: the full ±15° roll is fine.
4. Zero unreachable poses inside the URDF joint limits; no singularity in range.

## What the Isaac Lab side must add

Clip ankle torques with the diamond rule instead of two independent limits:

```python
# tau_p, tau_r = desired ankle pitch/roll torques (per leg)
s = abs(tau_p) / 72.0 + abs(tau_r) / 66.0
if s > 1.0:
    tau_p, tau_r = tau_p / s, tau_r / s
```

Optionally recompute the two limits per step from `ankle_map.joint_torque_limits(pitch, roll)`
to capture the configuration dependence (cheap: one 2×2 Jacobian). Without this clip, the
policy will learn to demand simultaneous max pitch + max roll, which the real robot cannot do.

## Deploy-time use

```python
from ankle_map import ik, fk
th1, th2 = ik(pitch_cmd, roll_cmd)     # -> the two RS06 position targets
pitch, roll = fk(th1_meas, th2_meas)   # motor feedback -> observation
```

Signs follow the URDF axes but must be confirmed once against the real actuators before the
first powered ankle test.

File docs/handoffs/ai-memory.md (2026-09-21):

# primo — open hardware humanoid — shared working memory

Last update: 2026-09-21.

> **GENERATED BONES (bonegen) + STANDARD MOTORS VS HOUSING-AS-BONE — 2026-09-21 evening (AI + user):** the user wants bones generated automatically instead of flat CAD plates: place the motors, then grow each bone between their screw holes by topology optimisation, clear of everything that moves, with screws insertable; goal stated by the user: **all bones generated and the robot walking with them in Isaac Lab, loads taken from the simulation**. Built `umanoide/bones/` (local venv) and published as `umanoide-release/cad/bonegen/`: `bonegen.py` (one file: voxelise, pads on the motor screw holes, swept keep-outs of the neighbours over the joint range + 3 mm clearance, counterbores and tool paths, multi-load-case SIMP, smooth mesh of equal volume, exact booleans), `thigh_free.json` (free mode: NO CAD bone as input), `thigh.json` (CAD-interface mode, only for the baseline), `render.py`, `README.md` = handoff and plan for the workstation. **User decisions:** standard mounting for every motor (one bone on the body/outer holes, the other on the output/inner holes, both on the output face); NO back mounting even where the body holes are through; free mode preferred over optimising the CAD bone. **Measured from the meshes:** RS06 output 6 x M4 on Ø24; RS04 body 10 x Ø4 on Ø106.6 through the lobes, mounting face 3.6 mm behind the rotor face; RS04 output 6 x Ø5 on Ø36 (check against RobStride drawings). CAD knee: femur plate y -129.4..-139.4 on the body holes, shank plate from -141.5 on a Ø50 hub through the femur ring, gap 2.1 mm -> femur screw heads MUST be counterbored. **The CAD femur touches the shank assembly from about 123 deg of knee flexion** (URDF limit 165 deg inherited from the reference robot; policy uses -5..116): joint limits to be decided. The CAD femur is 188.4 cm3 solid = 0.236 kg at 1.25 g/cm3. **Pilot result (Mac, 4 mm, ASSUMED loads, equal mass):** generated thigh vs CAD femur: lateral bending x1.75, torsion x1.47, knee torque x0.92, fore-aft x0.95, axial x0.59 (0.14 -> 0.24 mm under 2x body weight) = a draw overall; the flat plate is efficient in its plane and weak sideways. Needs 2 mm and real loads: work moves to the workstation (GPU, policy, forces). Isaac Lab cannot optimise bones while walking (rigid links): loop in rounds = loads from the policy -> bones -> new masses in the URDF -> fine-tune -> loads again. **Motors:** new `docs/actuator-integration.md`: standard modules and custom housing-as-bone actuators will coexist; penalty of standard = mass/bulk (RS04 ~84 Nm/kg vs ~189 custom; 45 kg vs 35 kg), not walking ability; future proof = motor as swappable interface + regenerated bones; clamping suits aluminium links, not PA-CF (heat, creep); integrated route = frameless kit (stator + rotor bought) + own housing, bearings, gearbox, encoders, driver; a complete low-reduction hollow-shaft actuator sold without housing is not a catalogue item as far as known (the housing carries ring gear and bearing seats); metal-printed housings need finish machining; suggested path: v1 standard, metal bones on hot joints, later one bench joint. Zip for the workstation on the Desktop: `primo-bonegen-workstation.zip`. Remote Control only mirrors this Mac session: it does not run commands on the workstation.
> **WRITING RULE (2026-09-21, user):** this file is English only. Call assistants "AI" / "AI session": no product or company name of any AI tool in this file or in any shared material (repository and its history, download package, bucket, listings), and no agent-specific entry file in the repository: `AGENTS.md` is the only one. Today: the memory was translated line by line (numbers, links and code spans checked automatically; Italian original kept in `outputs/memory-backups/`), the last Italian rows of the BOM got English text in `ROW_OVERRIDES`, the repository history was rewritten without those names, `primo.zip` rebuilt. The public copy is `docs/handoffs/ai-memory.md`: copy this file unchanged. Check before every push: `python3 publishing-upload/check_public.py --history`.
> **LOCOMOTION + MOTOR SELECTION NOW SHARED — 2026-09-21 (AI + user):** the user asked to share ALL the locomotion work ("the policy, the code, how we got there... everything") and the motor comparison. **(1) Locomotion:** the folder `umanoide/humanoid_locomotion/` (48 files, 11 MB, received from the Isaac workstation: policy `kneehard_model_2999.pt`, video, `params_as_trained/env.yaml+agent.yaml`, `code/tasks` + `code/assets` + `code/symmetry` + 14 diagnostic scripts, `HANDOFF.md` round by round, `LESSONS.md`, `RESULTS.md`, `NEXT_STEPS.md`, `setup/INSTALL.md`, `reference/`) has been copied BYTE-IDENTICAL into `umanoide-release/sim/isaaclab/` (it replaces the old placeholder "not in this folder yet"). Only addition: an "In this repository" section in `sim/isaaclab/README.md` (mapping `rl_full.urdf` = `sim/urdf/primo.urdf`; table of the `C:\Users\WKS\...` paths to be edited; policy I/O) + `sim/isaaclab/code/LICENSE`. **Facts VERIFIED today (not estimates):** from the checkpoint (tensor dimensions in the .pt zip) observation = **272** = lin vel 3 + ang vel 3 + gravity 3 + command 3 + joint pos 30 + joint vel 30 + last action 13 + height scan 187; action = **13** (12 legs + waist roll), target = default + 0.5 x action, **50 Hz** (dt 0.005 x decimation 4), MLP 512-256-128 ELU without obs. normalization; trained commands: forward 0-1.0 m/s, NO lateral, yaw +-1.0 rad/s via heading; joint order = the one resolved by Isaac Lab (`preserve_order: false`), to be read from the env before every deploy. The repo's foot mesh (`sim/meshes/Part_22_foot.stl`) has EXACTLY the extents expected by `simplify_foot_collision.py` (sole z = -0.7883, center x 0.0333, y -+0.1267, AABB 48.9 x 81.4 mm) -> `sim/urdf/primo.urdf` is the same export used for the training; it still has the mesh collision at the feet, so before converting to USD the script must be run on a copy. **License:** `code/assets`, `code/symmetry`, `code/tasks` have the Isaac Lab **BSD-3-Clause** header (text in `sim/isaaclab/code/LICENSE`); scripts, documents and policy remain CC0. No credentials/IPs in the files: only workstation paths. **NOT in the package (only on the workstation, optional because reproducible):** `rl_full_isaac/usd/rl_full.usd`, the URDF already patched at the feet, the checkpoints of the other runs (KneeTorque etc.), the tensorboard logs. **(2) Motors:** new `umanoide-release/docs/motor-selection.md` = short, public version of why RobStride: requirements, timeline 06-14 -> 06-23, Asimov's Encos map (5 models: A4310 x10, A4315 x4, A6416 x3, A5013-H x4, A3814-H x4), what Encos does better (Ø56/382 g vs Ø88/621 g at 36 Nm; -3.7 kg on the legs) and why it was NOT chosen (reduction 25-36:1 and harmonic drives 100:1 = reflected inertia 8x/16x/100x+, no backdrivability/force control and not upgradable via sw, worse on the ankle; quotation-only with no public CAD; ~3.5x the price; target moved from tethered ~28-30 kg to 45 kg with on-board battery, G1 class), RobStride vs CubeMars table by torque class, CubeMars dimensional error, other candidates, open points (hip yaw, AKE90-8 as a leg upgrade). Linked from the README (new "Motors" section), AGENTS.md, `docs/handoffs/README.md`, `docs/references.md` (new section with Asimov/Encos/CubeMars/Steadywin/MyActuator/ZeroErr/Dynamixel links). **CORRECTION to `MOTORI_TABELLE.md` (and its copy `docs/actuator-tables.md`):** it still had the headings "1. CHOSEN CONFIG — Encos" and "3b. CUBEMARS — CHOSEN SUPPLIER" and two CubeMars rows with the WRONG dimensions (AK70-9 "Ø70", AK40-10 "Ø46") = misleading for anyone who downloads it. Now: sect. 1 and 3b marked SUPERSEDED, sect. 4 RobStride = **CHOSEN**, wrong rows struck through and explained, "AKE90 Ø90" note corrected (Ø107.5: thinner, not slimmer). Backup of the previous file in the session scratchpad. **Asimov links:** `docs.menlo.ai/asimov/v1/bom` now returns 404 -> use `https://docs.menlo.ai/asimov/1`, `github.com/asimovinc/asimov-1`, `tally.so/r/jaG0va` (verified 200 on 2026-09-21). `Asimov 1 BOM.xlsx` and the vendor manuals are NOT redistributed. **Rule for the next sessions:** if `humanoid_locomotion/` gets updated from the workstation, copy it again into `sim/isaaclab/` with `rsync -a` while PRESERVING the "In this repository" section of the README and `code/LICENSE`, then rebuild `primo.zip` (now ~32 MB) and upload it to `gs://riverfamily/primo/`.
> **NAME = "primo" — PUBLICATION COMPLETED ON ALL PLATFORMS — 2026-09-19 evening (AI + user) [SUPERSEDES the two bullets below]:** the humanoid is called **primo** (chosen by the user among 10 proposals in the River Family style); listing title **"Primo open source humanoid robot"** (lowercase on the website and MakerOnline). GitHub repo renamed `AlessioPagliai/primo` (the old `umanoide` URL redirects); the local repo folder remains `~/Documents/artes/umanoide-release`. **COMMIT RULE:** author ONLY `Alessio Pagliai <alessiopagliai.d@gmail.com>`, NEVER a `Co-Authored-By: <AI name>` trailer nor the Mac's default identity (`utente1`); history of `primo` and the latest commits of `RiverFamily` rewritten and force-pushed on 2026-09-19; rule written in `~/Desktop/PUBLISH_GITHUB_AS_ALESSIO.md`. No "AI made" labels on the platforms. **URLs:** YouTube https://youtu.be/6nTcHpFmKbQ (4K60 H.264 closed-GOP, chapters; the two previous uploads were deleted by the user: the HEVC open-GOP master was being played back by YouTube in repeated 4 s blocks); website https://riverfamily.art/#primo (App Engine version `gallery-primo-20260919`: "more" = video only, GCS mp4 on desktop / YouTube iframe on mobile like the other designs; "make" = downloads `primo.zip`); Printables https://www.printables.com/model/1846831 (embedded video, 26 tags, 35 STL + 2 3MF); Thingiverse https://www.thingiverse.com/thing:7411626; Cults https://cults3d.com/en/3d-model/gadget/primo-open-source-humanoid (1:1 images, 30 s clip, CC0, free); Creality Cloud https://www.crealitycloud.com/it/model-detail/6aae7192f052c066aeb8dd96 (listing complete but REJECTED by moderation: the cover must be a real photo of the print; not visible to the public, therefore NOT linked in the docs; Creality has no drafts: the rejected listing stays private and editable and serves as a draft (the user said to leave it like this); when the photos are available: profile › 3D Model › ⋯ › Edit, photo as cover, name "Primo open source humanoid robot", resubmit); MakerOnline https://www.makeronline.com/en/model/primo%20open%20source%20humanoid/331171.html; MakerWorld: draft 9688828 resubmitted, again automatically REJECTED (no real photo) and then SAVED AS DRAFT at the user's request (3D Models › Draft; the old "umanoide" draft is also there, to be deleted by hand) — without a REAL PHOTO of a printed part it always gets rejected (the user will take the photos in a few days); the MakerWorld video slot does not accept programmatic upload: drag `publishing-upload/video/primo-30s.mp4` in by hand. **Self-contained shared folder:** `gs://riverfamily/primo/primo.zip` = the whole repo (README, AGENTS.md as the entry point for a new AI session, this memory in `docs/handoffs/ai-memory.md`, BOM + generator, electrical schematic, `cad/stl/` = ONLY the 20 parts to be printed, in mm, right+left = 35 STL; the purchased components are in the BOM and their meshes only in `sim/meshes/` for the URDF `sim/urdf/primo.urdf`, mirror pipeline, Isaac/teleop handoffs). MISSING from the repo: the Isaac Lab training code, which is on the workstation (placeholder `sim/isaaclab/README.md`). Other GCS files: `primo/primo-stl.zip`, `primo/videos/{primo-4k60,primo-30s,walk-kneehard,walk-kneetorque}.mp4`, `videos/Primo_720p.mp4` (website). Texts, tags and URL list: `umanoide-release/publishing/platform-texts.md`. Walking policy chosen: KneeHard. RiverFamily repo: removed the `SECRET_KEY` line from `app.yaml` (it was a placeholder not used by `app.py`, different from the key of the live site: no real secret exposed, no history rewrite needed); the Stripe `pk_live_` in `templates/index.html` is a publishable key by design. WARNING Printables: after every edit check that the description is not empty (the ProseMirror editor replaces the selected node: insert the video in an empty paragraph between two paragraphs, never with everything selected).
> **OPEN SOURCE PUBLICATION — RELEASE PACKAGE PREPARED — 2026-09-19 (AI + user):** the user is publishing the project today on GitHub (account `AlessioPagliai`), Printables/MakerWorld/Thingiverse (@River_Family / @RiverFamily), riverfamily.art and YouTube (@art.riverfamily). Style learned from his sites: **extreme minimalism, lowercase names, English, descriptions of 0-15 words, no marketing, CC0 license, large files on the GCS bucket `gs://riverfamily/`, links to all the platforms**. Working name: `umanoide`. Created a clean folder **`/Users/artes/Documents/artes/umanoide-release/`** (local git repo, 1 commit, 1.6 MB): `README.md` (numbers, phases/costs, files, sim, open points, license), `bom/` (bom.xlsx + bom.csv 108 active rows + build_bom.py), `electrical/` (scheme md/svg/png), `cad/` (README with Onshape link, `motor_proxy.fs`, `3mf/ankle-gimbal.3mf` = Bambu PPA-CF H2C 1 wall 90% grid, `3mf/leg-test-plate.3mf` = femur+hip bracket+tibia in PLA on H2S), `sim/` (mirror_urdf.py, ankle_map.py + ankle-transmission.md WITH WARNING "provisional geometry from mesh centroids", g1_joints_reference.csv), `docs/` (hand-design, actuator-tables, references.md with 27 arXiv papers + vendor links, `handoffs/` = isaac/teleop/mirror-debug + **ai-memory.md = copy of this MEMORY.md**), `publishing/platform-texts.md` (ready-made texts for each platform, catalogue.json entry, RiverFamily README block, list of images to be made in Onshape), `LICENSE.md` CC0 (copied from RiverFamily). **Deliberately EXCLUDED:** `sources/` (papers, 400 MB: list only), `motors/`+`hands/` (vendor manuals/STEP: links only), `hydrogen/` and `noetix_manual/` (unrelated projects), `Asimov 1 BOM`, `G1.blend`, `outputs/`. **Uploaded to GCS (public):** `gs://riverfamily/umanoide/umanoide-urdf.zip` (11.8 MB = rl_full: urdf+mesh+handoff) and `videos/walk-kneehard.mp4`, `walk-kneetorque.mp4`. BOM totals as of 2026-09-19 unchanged: remaining 10.264,90 / F1 4.008,57 / F2 3.997,95 / F3 2.258,38; mass 33,24 kg. **TO DO:** Onshape images/GIFs from the user (`images/hero.webp` referenced in the README), Onshape document made public, creation of the GitHub repo `AlessioPagliai/umanoide` + push (terminal NOT authenticated: `gh auth login` or a PAT is needed, or else upload via browser), 3MF upload to Printables/MakerWorld/Thingiverse, YouTube video, website entry. Locomotion policy note: `KneeHard.mp4` vs `KneeTorque.mp4` (compare_r5 = sweep KneeDefault/Soft/Hard + KneeTorque); config on the Isaac workstation, not here.
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

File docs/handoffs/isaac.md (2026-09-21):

# ISAAC_HANDOFF — rl_full.urdf (generated 2026-07-18)

> In this repository `rl_full.urdf` is [sim/urdf/primo.urdf](../../sim/urdf/primo.urdf) with its meshes in `sim/meshes/` (same file, robot name changed to `primo`).

For the AI session on the Isaac Sim PC. This folder is the **training-ready artifact**;
it is generated on the CAD Mac by `mirror_urdf.py` from the raw Onshape export. **Do NOT clean or
convert the raw `rl/rl.urdf` export — it is only the right half, with placeholder masses and no
limits. Everything you flagged (dummy links, placeholder masses, no collisions/limits) is already
fixed HERE.** Project source of truth: [ai-memory.md](ai-memory.md) in this folder.

## What rl_full.urdf contains

- Full robot: 131 links, 30 revolute joints — 6/leg ×2, 7/arm ×2, waist roll+yaw, neck yaw+pitch.
  Left side is an exact machine-verified mirror (0.000 mm on all 13 joint pairs).
- Semantic joint names: `right_hip_pitch_joint` … `left_wrist_yaw_joint`, `waist_roll_joint`,
  `waist_yaw_joint`, `neck_yaw_joint`, `neck_pitch_joint`.
- **Axis convention: same command = mirrored motion; left limits = right limits.**
- Ankle = two serial virtual joints (pitch above roll) at the offset gimbal — the real machine is a
  2×RS06 pushrod differential; the loop is intentionally omitted (project decision; motor-to-joint
  map applied at deploy).
- Masses injected from the BOM/manuals (total 32.25 kg incl. battery 2.27, Thor 1.94, WEHO/Eaton/
  LEV100/IMU). Inertias: geometric tensors scaled to real mass (uniform-density approx).
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

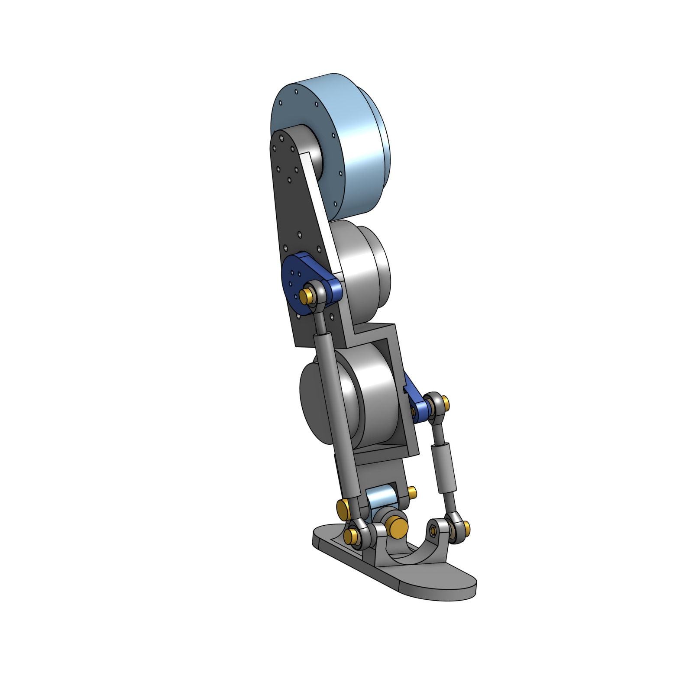
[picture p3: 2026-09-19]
publishing/images/ankle-1x1.jpg

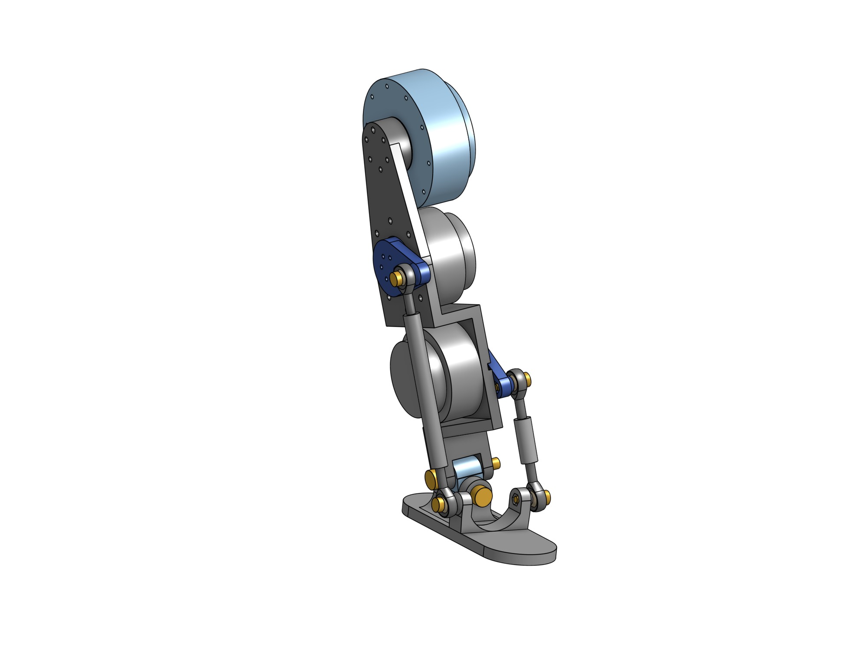
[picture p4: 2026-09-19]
publishing/images/ankle-4x3.jpg

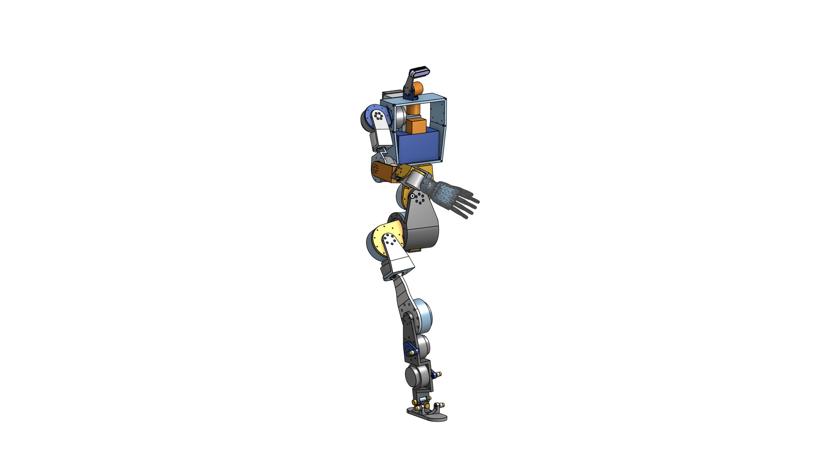
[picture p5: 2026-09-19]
publishing/images/pose-16x9.jpg

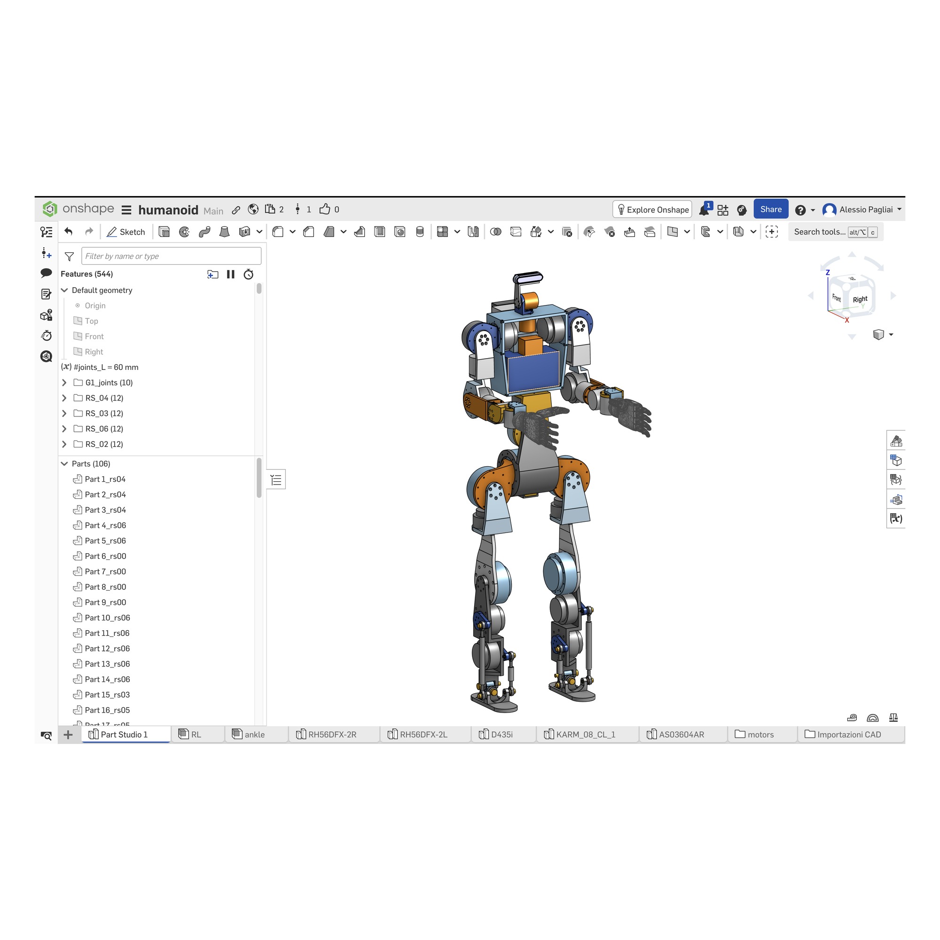
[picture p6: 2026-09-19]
publishing/images/cad-page-1x1.jpg

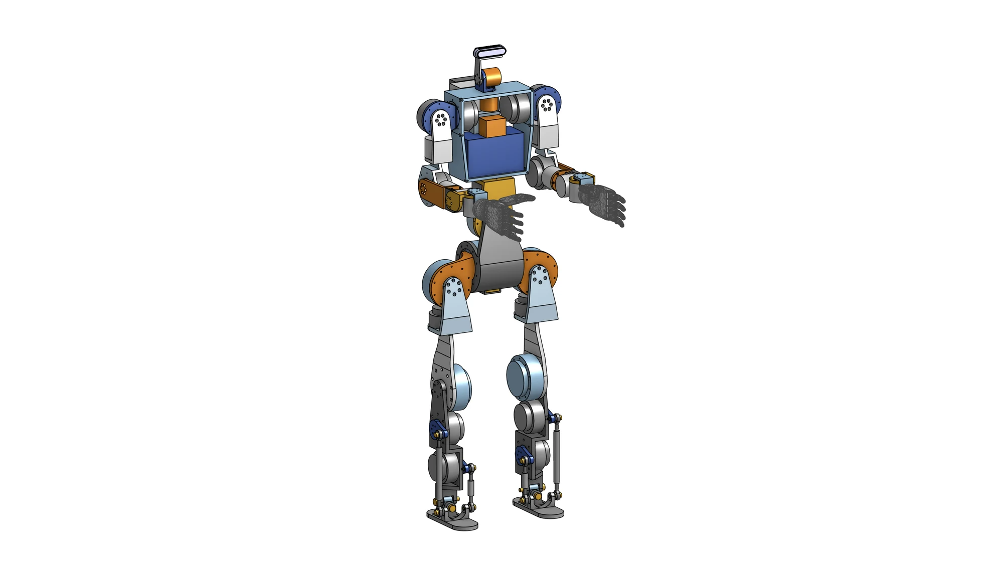
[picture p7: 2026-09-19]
publishing/images/hero-16x9.webp

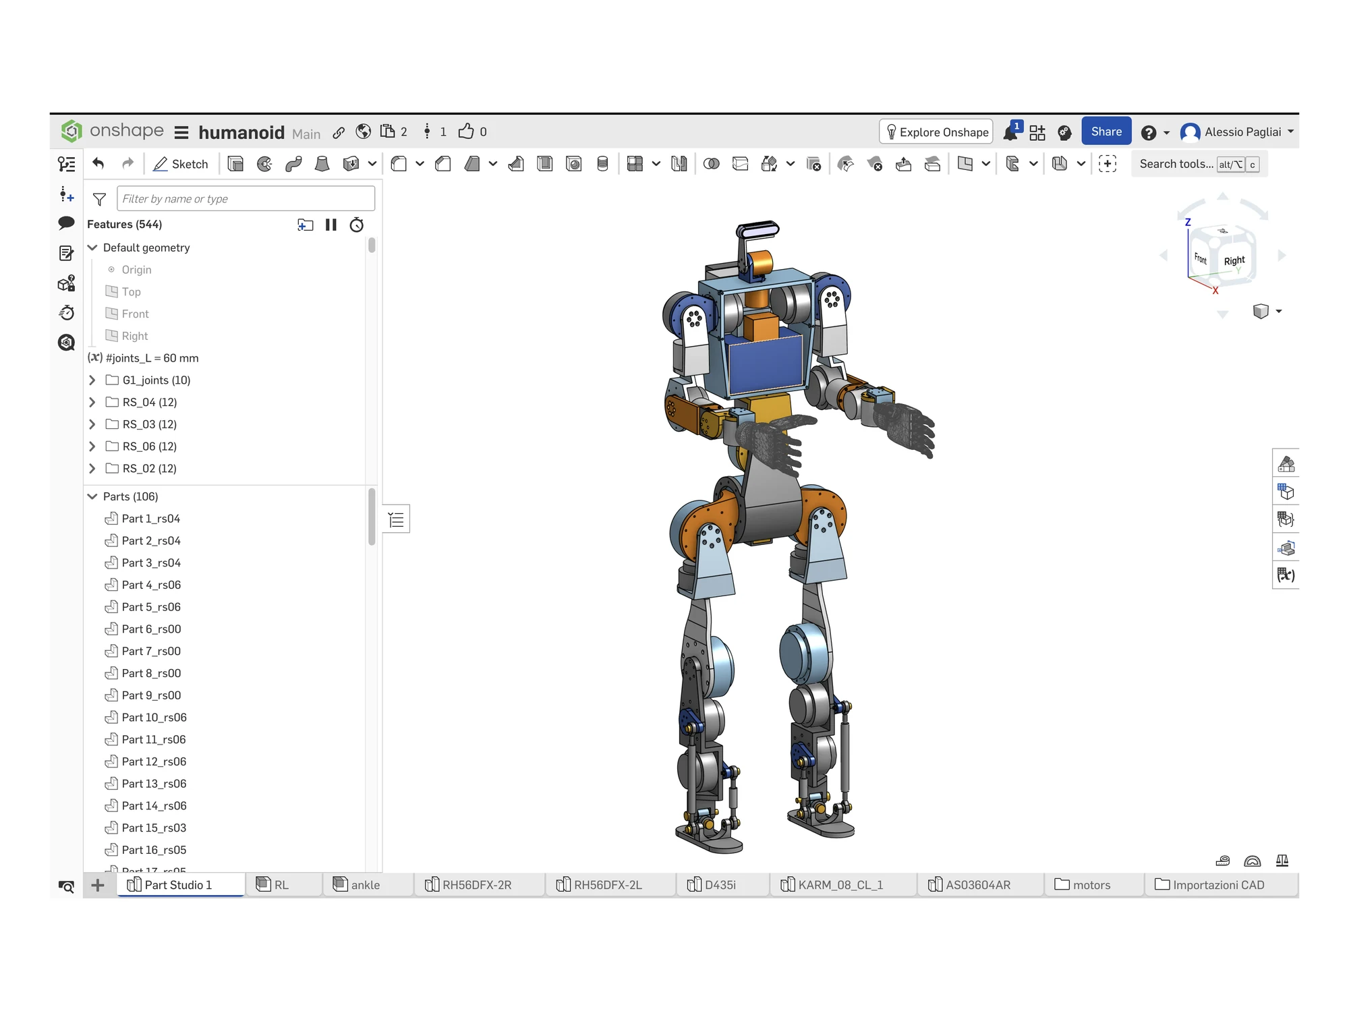
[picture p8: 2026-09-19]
publishing/images/cad-page-4x3.webp

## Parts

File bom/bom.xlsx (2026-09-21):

Item | Supplier | Unit cost | VAT/Duties | VAT/Duties amount | Qty | Total | Description / purpose | Notes | Category | Purchase link | Phase | Mass (kg) | CAD 3D
1 - MECHANICAL PROTOTYPE - 2-axis ankle offset gimbal + M8 pushrods
[SELECTED qty0] Ankle foot-shin 2-axis offset gimbal - igus sliding bush concept (decision 2026-06-03, updated to Ø8/M6 pins) | internal print + standard hardware | €0.00 | 22% |  | 0 |  | Selected architecture: compact 2-axis ankle gimbal with two Ø8/M6 shoulder screws stacked in Z, not a perfect intersecting-axis universal joint. Higher-Z 45 mm pin = pitch axis; lower-Z 45 mm pin = roll axis. The gimbal pins are not the same function as the pushrods: gimbal pins define the foot-shin joint axes; pushrod pins carry the rod-end spherical bearings. | Current pin choice from user update 2026-06-27: Ø8/M6 black shoulder screws from AliExpress, 2 x 45 mm for the ankle gimbal and 4 x 16 mm for the pushrod rod-end pivots, plus 6 M6 retaining nuts. Pushrod length adjustment uses M8 right-hand/left-hand rod-end threads plus 4 x M8 DIN 439 thin jam nuts. Model the real pitch/roll Z offset in CAD/simulation; do not assume an ideal single-center Cardan map. Bushing/bearing choice still depends on the CAD stack-up. | Mechanical | https://github.com/unitreerobotics/unitree_ros/blob/master/robots/g1_description/g1_29dof_mode_11.urdf | Phase 1
[ALT qty0] SKF PCM 121420 E - PTFE composite plain bushing 12x14x20 mm | Cuscinetti and Componenti | €2.13 | 22% |  | 0 |  | Real example of a thin plain bushing for a 12 mm diameter shaft of the foot-shin joint: bore 12 mm, outer diameter 14 mm, length 20 mm. | Exact SKU SKF PCM121420E. Price verified 2026-06-02: EUR 2.13 net (excluding VAT). Candidate alternative for slow oscillation; qty 0 until CAD, loads, pin-seat fit and axial control are defined. | Mechanical | https://cuscinettiecomponenti.it/prodotto/pcm-121420-e-boccole-di-usura-12x14x20-skf/ | Phase 1
[ALT qty0] SKF PCM 121425 E - PTFE composite plain bushing 12x14x25 mm | Cuscinetti and Componenti | €2.94 | 22% |  | 0 |  | Longer real example from the same family: bore 12 mm, outer diameter 14 mm, length 25 mm. It shows that a single 25 mm long bushing is a standard component. | Exact SKU SKF PCM121425E. Price verified 2026-06-02: EUR 2.94 net (excluding VAT). Qty 0: the greater length is not automatically better if it introduces misalignment or if the CAD does not provide a correct seat. | Mechanical | https://cuscinettiecomponenti.it/prodotto/pcm-121425-e-boccole-di-usura-12x14x25-skf/ | Phase 1
[ALT qty0] igus iglidur Q2SM-1214-20 - heavy-duty polymer bushing 12x14x20 mm | igus / EBMiA | €6.15 | 22% |  | 0 |  | Self-lubricating polymer example for a 12 mm diameter shaft: outer diameter 14 mm, length 20 mm. The Q2 material is developed for pivoting applications with dynamic loads, shocks and dirt. | Exact SKU igus Q2SM-1214-20. Price verified 2026-06-02: PLN 25.89 net (excluding VAT), about EUR 6.15. Qty 0: verify surface pressure, wear, seat and tolerances with the igus tool before selection. | Mechanical | https://www.ebmia.pl/tuleje-slizgowe-iglidur-q2/199876-tuleja-slizgowa-q2sm-1214-20.html | Phase 1
[ALT qty0] igus iglidur Q2FM-1214-12 - heavy-duty flanged bushing 12x14x12 mm | igus | €0.00 | 22% |  | 0 |  | Example of a flanged plain bushing for a 12 mm diameter pin: it guides the radial load and provides an integrated axial stop. Dimensions: bore 12 mm, outer diameter 14 mm, length 12 mm, flange diameter 20 mm, 1 mm thick. | Exact SKU igus Q2FM-1214-12. Qty 0: useful if the CAD allows one bushing inserted from each side of the moving part; do not assume that two 12 mm pieces fit in the available width. Q2 is indicated by igus for high loads, shocks, dirt and heavily stressed pivoting applications. | Mechanical | https://www.igus.co.uk/iglidur-ibh/flanged-bearings/product-details/iglidur-q2-m?artnr=Q2FM-1214-12 | Phase 1
[ARCHIVED qty0] igus GTM-1224-015 - separate thrust washer (superseded: axial now in the flange) 12x24x1.5 mm | Conrad | €1.22 | 22% |  | 0 |  | Separate plain thrust washer to be located on the central moving part, between it and each outer lug, when the radial bushing has no flange. It puts the axial sliding on a surface designed for the purpose. | Exact SKU igus GTM-1224-015: bore 12 mm, outer diameter 24 mm, thickness 1.5 mm. Price verified 2026-06-02: EUR 1.49 VAT included at Conrad. Qty 0: do not leave it loose between two PA-CF faces. Provide a locating seat and a fixed, smooth, replaceable metal counterface in the lug; define the axial play in the CAD. | Mechanical | https://www.conrad.com/en/p/igus-gtm-1224-015-shim-ring-bore-diameter-12-mm-1416586.html | Phase 1
[ARCHIVED qty0] SKF HK 1216.2RS - needle roller bearing without inner ring (superseded) 12x18x16 mm | Cuscinetti and Componenti | €0.00 | 22% |  | 0 |  | Compact rolling alternative for the radial load only of the 12 mm diameter pin. It must be housed either in the moving part or in the pair of lugs, not in both at the same time. It has no inner ring to clamp between the shoulders of the lugs. | Exact SKU SKF HK1216.2RS: bore 12 mm, outer diameter 18 mm, length 16 mm, seals on both sides. Availability verified 2026-06-02: 21 pieces, price on quotation. Qty 0: it requires the fixed pin to be a suitable hardened and ground inner raceway; do not automatically let the needle rollers run on a screw or a raw pin. It is not the first choice if you want to clamp shoulders against a true inner ring. | Mechanical | https://cuscinettiecomponenti.it/prodotto/hk-1216-2rs-cuscinetti-a-rullini-12x18x16-skf/ | Phase 1
[ARCHIVED qty0] SKF NKI 12/16 - needle roller bearing with inner ring (superseded by the flanged igus plain bushing) 12x24x16 mm | Klium | €22.15 | 22% |  | 0 |  | First simple architecture to draw: bearing in the central moving part; separable inner ring clamped between the integrated shoulders of the two PA-CF lugs; outer ring seated in the moving centre. It carries the radial load without requiring metal caps in the lugs. | Exact SKU SKF NKI 12/16: bore 12 mm, outer diameter 24 mm, width 16 mm, inner ring included. Price verified 2026-06-02: EUR 22.15 net (excluding VAT) at Klium. Qty 0 until the CAD. The shoulders must clamp the inner ring without crushing the central moving part; the running clearance is between the moving part and the lugs, not between the shoulders and the inner ring. NKI is not a thrust bearing: if tests show axial contact, add located igus thrust washers or a separate thrust bearing. | Mechanical | https://www.klium.nl/en/skf-nki-12-16-needle-roller-bearing-with-inner-ring-12x24x16-mm-41676 | Phase 1
[ARCHIVED qty0] SKF AXK 1226 - thrust bearing (superseded: axial now in the flange) 12x26x2 mm | RS Italia | €4.10 | 22% |  | 0 |  | Rolling alternative for axial load: one thrust bearing cage for each side of the central moving part if the CAD requires very low axial friction. | Exact SKU SKF AXK 1226: bore 12 mm, outer diameter 26 mm, thickness 2 mm, dynamic load 9.15 kN and static 30 kN. Price verified 2026-06-02: EUR 4.10 net (excluding VAT) at RS Italia. Qty 0: between printed faces use two hardened AS 1226 washers for each cage. | Mechanical | https://it.rs-online.com/web/p/cuscinetti-a-rulli/0514243 | Phase 1
[ARCHIVED qty0] SKF AS 1226 - hardened thrust washer for AXK (superseded) 12x26x1 mm | Cuscinetti and Componenti | €1.86 | 22% |  | 0 |  | Hardened axial raceway for the AXK 1226 cage. With PA-CF or polymer faces do not use the printed part directly as the raceway for the needle rollers. | Exact SKU SKF AS1226: bore 12 mm, outer diameter 26 mm, thickness 1 mm. Price and stock verified 2026-06-02: EUR 1.86 net (excluding VAT), 13 pieces available. Qty 0: a complete solution per side takes up 1 + 2 + 1 = 4 mm: AS 1226 + AXK 1226 + AS 1226. | Mechanical | https://cuscinettiecomponenti.it/prodotto/as-1226-cuscinetti-a-rullini-12x26x1-skf/ | Phase 1
[ARCHIVED qty0] HGI PS 12x18x1 DIN 988 - adjustment shim washer (superseded) | Cuscinetti.net | €0.48 | 22% |  | 0 |  | Metal shim washer to calibrate the residual axial play after choosing the thrust surface. It does not replace an igus plain thrust washer or a hardened raceway for AXK. | Exact SKU HGI12X18X1 / PS12X18X1: bore 12 mm, outer diameter 18 mm, thickness 1 mm. Price and stock verified 2026-06-02: EUR 0.48 net (excluding VAT), 57 pieces. Qty 0: choose the final combination only after measuring the assembly; DIN 988 also exists in finer thicknesses, for example 0.2 mm. | Mechanical | https://www.cuscinetti.net/e-catalogue/181768-rondella-di-spessoramento-ps-12x18x1-din-988-hgi.html | Phase 1
[ALT TO SIZE qty0] Fixed flanged metal inserts in the ankle lugs - counterfaces for 12 mm diam. axis | Elesa+Ganter DIN 172 / lavorazione custom | €0.00 | 22% |  | 0 |  | Two cap-shaped inserts per axis, pressed or located in the outer PA-CF lugs: the inner bore guides or contains the fixed 12 mm diameter pin; the flange facing the central part provides a smooth metal axial counterface for the igus thrust washer. | Alternative to keep documented if the printed central igus bushing is used or if the PA-CF shoulders prove insufficient. Preliminary CAD reference: left lug about 20 mm + central moving part with bushing about 20 mm + right lug about 20 mm = about 60 mm of structural bodies. The caps go on both lugs. Caution: a protruding flange increases the stack; recess it into the lug if you want to stay close to 60 mm. The cap bore guides the pin but does not automatically make it integral with the lugs: also design anti-rotation and axial retention. | Mechanical | https://www.elesa.com/siteassets/PDF/PDF_IT/DIN%20172.pdf | Phase 1
[OPTIONAL UPGRADE qty0] Elesa+Ganter GN.12825 / DIN 172-B12-20-A - metal counterface in the lug, bore 12 L20 | Verzolla Italia | €6.89 | 22% |  | 0 |  | Standard candidate for each lug if the central igus bushing is printed: hardened cap-type guide bush, inner bore 12 mm F7, outer diameter 18 mm n6, flange diameter 22 mm, body 20 mm long and flange 4 mm thick. | Exact SKU Elesa+Ganter DIN172-B12-20-A / GN.12825, Verzolla code Y1137. Price and availability verified 2026-06-02: EUR 6.89 each, 5 available. Qty 0: expected quantity if used on both axes and on both ankles = 8 pieces, but activate only after CAD. To keep the about 60 mm reference, recess the 4 mm flange into the lug; also verify counterface, fit in the PA-CF and anti-rotation of the pin. | Mechanical | https://www.verzolla.com/elesa-bussola-di-guida-flangiata-din172-b12-20-a-y1137 | Phase 1
[ALT SUPPLIER qty0] Otto Ganter 172-B12-20-A - flanged metal cap, bore 12 mm, L20 | Best4Automation | €5.26 | 22% |  | 0 |  | Second supplier of the same standardized DIN 172-B12-20-A cap: steel, bore 12 mm, outer diameter 18 mm, flange 22 mm, body length 20 mm, flange 4 mm. | Exact product Ganter 172-B12-20-A. Price and delivery verified 2026-06-02: EUR 5.26 net (excluding VAT) each, indicated as shippable in 2-3 working days; B2B sales. Qty 0: sourcing alternative for the same Verzolla component. | Mechanical | https://www.best4automation.com/positionierbuchse-mit-bund-bohrung-eins.-gerundet-sc-4042-172-b12-20-a/ | Phase 1
[ALT EQUIVALENT qty0] KIPP K1022.A1200X20 - flanged metal cap DIN 172, bore 12 mm, L20 | Normteile Leinigen | €4.50 | 22% |  | 0 |  | DIN 172 form A equivalent from another manufacturer for the same preliminary sizing: steel cap-type bush with inner bore 12 mm and length 20 mm. | Exact SKU KIPP K1022.A1200X20. Price and availability verified 2026-06-02: EUR 4.50 net (excluding VAT) / EUR 5.36 VAT included each, indicated as available with delivery in 2-5 days. Qty 0: standard alternative to be verified dimensionally against the KIPP drawing before ordering. | Mechanical | https://www.normteile-leinigen.de/Bundbohrbuchse-12-x-20-DIN-172-Form-A/K1022.A1200X20 | Phase 1
[DATASHEET qty0] Elesa+Ganter DIN 172-B12-20-A - TME technical page | TME | €9.27 | 22% |  | 0 |  | Technical page of a further distributor for the same Ganter cap: hardened steel, inner bore 12 mm, outer diameter 18 mm, flange 22 mm, length 20 mm. | Exact SKU TME DIN172-B12-20-A. Verified 2026-06-02: USD 10.04 about EUR 9.27 each, but TME stock indicated as zero. Keep it as a technical catalogue and as a backup for availability requests, not as an immediate primary supplier. | Mechanical | https://www.tme.eu/en/details/din172-b12-20-a/indexing-plungers/elesa-ganter/din-172-b12-20-a/ | Phase 1
[ALT CUSTOM qty0] 3D printed plain bushing in igus iglidur i150 | igus / stampa interna | €0.00 | 22% |  | 0 |  | First printable custom test piece for the 12 mm diameter axes of the foot-shin joint. It allows iterating on length, flange and play. i150 is the easiest igus tribofilament to process. | Material confirmed among those the user is purchasing for comparison. Qty 0: it is not yet the final choice. Validate surface pressure, wear, print orientation, pin finish, tolerances and play; do not automatically assume equivalence with injection-moulded Q2 or SKF metal/PTFE. | Mechanical | https://www.igus.eu/product/iglidur_I150_PF | Phase 1
[ALT CUSTOM qty0] 3D printed plain bushing in igus iglidur i190 | igus / stampa interna | €0.00 | 22% |  | 0 |  | Second printable custom test piece for the 12 mm diameter axes of the foot-shin joint. i190 is the candidate to compare when greater mechanical strength and wear resistance are needed. | Material confirmed among those the user is purchasing for comparison. Qty 0: it is not yet the final choice. The filament is sensitive to moisture: follow igus drying and instructions. Validate surface pressure, wear, orientation, tolerances and play. | Mechanical | https://www.igus.eu/product/iglidur_I190_PF | Phase 1
[CHOSEN PRIMARY qty0] PRINTED multi-material bushing J260+PA-CF, integral (radial + axial flange) | igus / stampa interna | €0.00 | 22% |  | 0 |  | PRIMARY approach chosen: print the bushing directly integral with the PA-CF moving part in multi-material FDM, with J260 both on the bore (radial) and on the flange faces (axial). No purchase if the print holds up. | J260-PF filament already purchased by the user. igus indicates extrusion ~280 C, bed ~120 C, heated chamber preferable. To be validated specifically: adhesion at the J260/PA-CF interface (main risk of multi-material), print orientation for roundness and bore wear, finish and actual Ø (plan for reaming/calibration), surface pressure, play. Qty 0: handled by the filament, not by an SKU. i150 and i190 remain comparison test pieces. | Mechanical | https://www.igus.eu/product/716 | Phase 1
[CHOSEN FALLBACK qty0] igus GFM-1214 flanged bushing (iglidur G) - radial + axial, purchasable | igus / RS / Misumi / Minetti | €0.00 | 22% |  | 0 |  | PURCHASED version of the flanged bushing, fallback if the J260 multi-material print does not hold up: bore 12, outer diameter 14, flange about 20 x 1. The flange handles the axial load; two per axis, flanges facing outwards, press-fitted into the moving part. Drop-in with the same dimensions: Q2FM-1214 (heavy-duty shocks/dirt), JFM-1214 (low friction). | SKU family GFM-1214 iglidur G. Length b1 from the CAD (e.g. two of 9-10 mm in a 20 mm moving part). Multiple suppliers verified 2026-06-03: igus direct, RS, Misumi IT, Minetti, F.lli Bono, Solema, ERIKS. Qty 0 until the CAD gives the lengths; expected quantity 8 (2 per axis x 4 axes) only if they are bought instead of printed. Retention: interference in the seat + stop flange; never cyanoacrylate, at most Loctite 603/638. Price to be verified once the length is configured. | Mechanical | https://www.igus.eu/iglide-ibh/flanged-bearings/product-details/iglidur-g-m | Phase 1
[SECOND SOURCE qty0] AliExpress black shoulder screw listing - old backup source for shoulder screws | AliExpress | €3.00 | 22% |  | 0 |  | Backup purchase listing for black shoulder screws. The current first choice is the newer AliExpress listing in the active Ø8/M6 rows below. | Kept as second source only. Do not use the old Ø12/M10 ankle-axis assumption for the current CAD unless the ankle is deliberately redesigned around Ø12 pins again. | Mechanical | https://it.aliexpress.com/item/1005007481484485.html | Phase 1
[CATALOGUE qty0] RS PRO 822-9316 - shoulder screw M10, shoulder diam. 12 x 20 mm | RS Italia | €7.93 | 22% |  | 0 |  | Purchasable industrial example of a shoulder screw: M10 thread, shoulder diameter 12 mm, shoulder length 20 mm, black steel class 12.9. | Exact SKU RS PRO 822-9316. Price verified 2026-06-02: EUR 31.71 net (excluding VAT) per bag of four, EUR 7.928 each. Qty 0: the 20 mm length is only a catalogue reference; choose the actual length after the CAD. | Mechanical | https://it.rs-online.com/web/p/viti-a-colletto/8229316 | Phase 1
[ALT qty0] RS PRO 292-417 - shoulder screw ISO 7379 M10, shank Ø12 x 60 mm (industrial alternative to the black AliExpress one) | RS Italia | €7.91 | 22% |  | 0 |  | Reference close to the first ankle CAD stack of about 60 mm: ISO 7379 screw with a plain section of diameter 12 mm and length 60 mm, thread M10 x 16 mm, head diameter 18 x 8 mm, total length 84 mm. | Exact SKU RS PRO 292-417, ISO 7379 shank Ø12 x 60, thread M10 x 16, head Ø18 x 8. Industrial ALTERNATIVE (the chosen pin is now the black AliExpress shoulder screw Ø12xM10): it acts as the raceway on which the igus slides and as retention. Made integral with the lugs by clamping (M10 nut + Loctite 243), not by press-fitting; shank-to-lug-bore fit sliding-locked (snug), no strong interference in the PA-CF. Expected qty 4 (one axis each) + spares, but qty 0 until the CAD fixes the shoulder length (~60-70). Alternative suppliers ISO 7379-12-M10: Rubix GN.35185, Elesa, Puntoviti, Berardi, KIPP. | Mechanical | https://it.rs-online.com/web/p/viti-a-colletto/0292417 | Phase 1
[CATALOGUE qty0] Motedis 12h6 - precision shaft diam. 12 mm h6 hardened and ground | Motedis | €0.00 | 22% |  | 0 |  | Alternative to be cut to size when a headless cylindrical fixed pin is needed. Also useful as a hardened and ground raceway if an HK bearing without inner ring is being considered. | Motedis product code 12h6. Qty 0: price dependent on the cut length. Define length and retention; it does not automatically replace a shoulder screw. | Mechanical | https://www.motedis.it/it/Albero-di-precisione-12-mm-h6-acciaio-temprato-e-rettificato | Phase 1
[CATALOGUE qty0] Wurth DIN 6325 / ISO 8734 - hardened dowel pin diam. 12 mm | Wurth | €0.00 | 22% |  | 0 |  | Industrial family of hardened and ground dowel pins, tolerance m6. The linked page shows the diameter 12 x 20 mm example; the family offers other lengths. | Catalogue useful for the CAD, qty 0. Wurth notes that DIN 6325 has been replaced by DIN EN ISO 8734. Do not choose 20 mm just because it is the linked variant: first measure the width of the assembly and design the retention. | Mechanical | https://eshop.wurth.fr/Goupille-cylindrique-DIN-6325-acier-brut-GOUPILLE-CYL-DIN6325-M6-12X20/025201220.sku/fr/FR/EUR/ | Phase 1
[TO SIZE qty0] Pin retainers and supports for the ankle joint | Amazon / Ruland / piastrina custom | €0.00 | 22% |  | 0 |  | Removable retainers for the two rotation axes of the foot-shin joint. | Historical catalogue restored: assortment of internal/external circlips. Provide a printed shoulder or metal insert on one side and a removable retainer on the other. Do not assume M10 nut, circlip, collar or plate before the CAD: the system depends on the type of pin and on the actual seats. | Mechanical | https://www.amazon.it/ANELLI-ELASTICI-INTERNI-ESTERNI-ASSORTITI/dp/B09CZKWD5J | Phase 1
[CHOSEN RETENTION qty0] BLACK M10 self-locking nut DIN 985 + Loctite 243 - clamps the Ø12xM10 axes (ankle + waist gimbal) | Amazon / AliExpress | €0.30 | 22% |  | 0 |  | End retention of the Ø12xM10 rotation axes: the M10 nut clamps the thread of the shoulder screw and makes it integral with the lugs (4 ankle axes + 2 waist gimbal). | CHOSEN retention: BLACK M10 self-locking nut (DIN 985, nylock set M3-M16) + Loctite 243. Expected qty 6 (4 ankle + 2 waist gimbal) + spares; qty 0 until CAD. Clean variant: thread into a metal insert embedded in the far lug, so that the clamping reacts on metal and does not compress the PA-CF. | Mechanical | https://www.amazon.it/Acciaio-Controdado-Esagonale-Inserto-Autobloccante/dp/B0C8ZCR6B1 | Phase 1
M6 nuts for Ø8/M6 shoulder screws - ankle gimbal + pushrod pivots | Amazon / AliExpress | €0.20 | 22% |  | 6 |  | Six standard M6 nuts for the selected Ø8/M6 shoulder screws: 2 nuts for the 45 mm ankle gimbal screws and 4 nuts for the 16 mm pushrod rod-end pivot screws. Geometry to reserve in CAD: M6 hex across flats 10 mm, circumscribed hex diameter about 11.55 mm; normal M6 locknut height is about 6 mm. | These M6 nuts retain the shoulder screws only; they are not the pushrod length-adjustment jam nuts. Use locknuts or standard M6 nuts with Loctite 243 after checking that the shoulder, not the threaded section, defines the working width. The nut must clamp the screw stack without crushing the rod-end spherical bearing. | Mechanical | https://www.amazon.it/Acciaio-Controdado-Esagonale-Inserto-Autobloccante/dp/B0C8ZCR6B1 | Phase 1
[CATALOGUE qty0] RS PRO 797-6254 - large washer M10 DIN 9021 stainless steel, 10.5x30x2.5 mm | RS Italia | €0.00 | 22% |  | 0 |  | Large washer to be evaluated under the head and nut of the shoulder screw to distribute the clamping over the outer surfaces of the PA-CF lugs. | Exact SKU RS PRO 797-6254: bore 10.5 mm, outer diameter 30 mm, thickness 2.5 mm, stainless steel A2, DIN 9021. Qty 0: verify space and quantity after CAD. Do not use the clamping to significantly bend the lugs: the pin is held by axial clamping at nominal dimension. | Mechanical | https://it.rs-online.com/web/p/rondelle/7976254 | Phase 1
[CATALOGUE qty0] Ruland MSP-12-F - removable split collar for pin diam. 12 mm | Ruland | €8.65 | 22% |  | 0 |  | Two-piece collar for retention or axial adjustment of a 12 mm diameter cylindrical pin when the external space allows it. Outer diameter 28 mm, width 11 mm. | Exact SKU MSP-12-F. Price verified 2026-06-02: USD 9.39 about EUR 8.65. Qty 0: it is a purchasable reference, not the automatic choice; verify external envelope and axial loads. | Mechanical | https://www.ruland.com/msp-12-f.html | Phase 1
AliExpress adjustable aluminum M8 pushrod - 140 mm ankle link | AliExpress | €7.00 | 22% |  | 2 |  | Adjustable aluminum M8 pushrod/link for the parallel/differential ankle. Selected long variant: 140 mm. CAD body mass estimate: 23.8 g each, excluding the separately listed igubal ends and M8 jam nuts. | Length-dependent estimate, not the incorrect former generic 90 g: 6061-class aluminium tube assumed OD 12 mm, ID 8 mm, density 2.70 g/cm3 gives 0.1696 g/mm x 140 mm = 23.8 g. Confirm the delivered tube OD/ID and whether the advertised 140 mm is body length or eye-to-eye, then replace this estimate with a scale measurement. Turnbuckle adjustment requires one M8 RH and one M8 LH end. | Mechanical | https://it.aliexpress.com/item/1005008935554718.html | Phase 1 | 0.048
AliExpress adjustable aluminum M8 pushrod - 40 mm ankle link | AliExpress | €7.00 | 22% |  | 2 |  | Adjustable aluminum M8 pushrod/link for the parallel/differential ankle. Selected short variant: 40 mm. CAD body mass estimate: 6.8 g each, excluding the separately listed igubal ends and M8 jam nuts. | Length-dependent estimate, not the incorrect former generic 90 g: same assumed OD 12 mm / ID 8 mm 6061-class aluminium tube gives 0.1696 g/mm x 40 mm = 6.8 g. Confirm delivered geometry and enough thread engagement/misalignment margin, then replace with a scale measurement. The selected spherical ends are separate igus RH/LH M8 rows. | Mechanical | https://it.aliexpress.com/item/1005008935554718.html | Phase 1 | 0.014
[ALT qty0] SKF SA8E rod end M8 right-hand, bore 8 mm | SKF | €8.00 | 22% |  | 0 |  | Precision upgrade, foot side. | Use together with SAL8E and turnbuckle tube. | Mechanical | https://www.acorn-ind.co.uk/p/skf/rod-ends-with-male-thread/sa8e-skf/ | Phase 1
[ALT qty0] SKF SAL8E rod end M8 left-hand, bore 8 mm | SKF | €10.00 | 22% |  | 0 |  | Precision upgrade, motor side. | Opposite right/left threads for adjustment. | Mechanical | https://www.acorn-ind.co.uk/p/skf/rod-ends-with-male-thread/sal8e-skf/ | Phase 1
[ALT qty0] Turnbuckle tube M8 DIN 1478 | mbo Osswald | €9.00 | 22% |  | 0 |  | Pushrod body for the SKF upgrade. |  | Mechanical | https://www.mbo-osswald.de/en/configurators/joint-rod-configurator | Phase 1
igus igubal KARM-08 CL / KARM_08_CL_1 - M8 right-hand male rod end, Ø8 bore, ±35° | igus | €0.00 | 22% |  | 2 |  | Selected right-hand spherical rod ends for the ankle pushrods: igus igubal KARM-08 CL, model KARM_08_CL_1, male M8 right-hand thread, Ø8 E10 ball bore for the Ø8/M6 shoulder screws, pivot angle ±35°, weight 6.2 g each. | Active user choice 2026-06-27, corrected 2026-06-27 for turnbuckle adjustment: qty 2 right-hand ends. Pair one KARM right-hand end with one KALM left-hand end per pushrod so rotating the aluminum body changes length. Plastic housing igumid G with iglide L280 ball. Loads from igus catalog: 1.7 kN short-term / 0.85 kN continuous in tension. Price is left 0 until the exact igus cart/quote is confirmed. | Mechanical | https://www.igus.com/product?artNr=KARM-08-CL | Phase 1 | 0.012
igus igubal KALM-08 CL - M8 left-hand male rod end, Ø8 bore, ±35° | igus / ERIKS | €0.00 | 22% |  | 2 |  | Selected left-hand spherical rod ends for the ankle pushrods: igus igubal KALM-08 CL family, male M8 left-hand thread, Ø8 E10 ball bore for the Ø8/M6 shoulder screws, target pivot angle ±35° matching the KARM-08 CL geometry. | Active qty 2 as the left-hand mate to the two KARM right-hand ends. Availability must be confirmed before ordering: older igus catalog text says KALM-CL left-hand was in preparation, while distributors list KALM-08-CL-J. If KALM-08-CL cannot be bought, fallback is either keep the stock left-hand metal rod end on the low-angle side or redesign the rod body/adapters; do not replace this with a female KBLM/KBRM part unless the pushrod body changes to male threaded studs. | Mechanical | https://shop.eriks.de/de/waelzlager-gelenklager-und-gelenkkoepfe-gelenkkoepfe/gelenkkopf-wartungsfrei-igumid-g-iglidur-j-aussengewinde-links-serie-kalm-cl-j-p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 | Phase 1 | 0.012
DIN 439 M8 thin jam nut, right-hand thread - pushrod length lock | Accu / Fabory | €0.50 | 22% |  | 2 |  | Thin right-hand jam nuts for locking the two KARM-08 right-hand rod ends after pushrod length adjustment. Standard DIN 439 / ISO 4035 M8 x 1.25 geometry: height along thread 4.0 mm, across flats 13 mm, circumscribed hex diameter about 15.0 mm. | Use one jam nut on each right-hand rod end. This is M8, not M6, because it locks on the rod-end external thread. Final supplier/finish can be generic DIN 439 A2/A4 or zinc steel; CAD clearance should reserve the 15 mm circumscribed diameter. [Checked 2026-07-19: no verified big-store equivalent for the LEFT-hand thin nut; specialist source kept. Before ordering, check whether the AliExpress pushrod kit already includes RH+LH jam nuts.] | Mechanical | https://www.accu.co.uk/thin-hexagon-nuts/73062-HFN-M8-A2 | Phase 1 | 0.004
DIN 439 M8 thin jam nut, left-hand thread - pushrod length lock | Accu / Fabory | €0.50 | 22% |  | 2 |  | Thin left-hand jam nuts for locking the two KALM-08 left-hand rod ends after pushrod length adjustment. Standard DIN 439 / ISO 4035 M8 x 1.25 left-hand geometry: height along thread 4.0 mm, across flats 13 mm, circumscribed hex diameter about 15.0 mm. | Use one jam nut on each left-hand rod end. A normal right-hand nut will not fit the KALM left-hand thread. CAD clearance should reserve the 15 mm circumscribed diameter and wrench access to the 13 mm flats. [Checked 2026-07-19: no verified big-store equivalent for the LEFT-hand thin nut; specialist source kept. Before ordering, check whether the AliExpress pushrod kit already includes RH+LH jam nuts.] | Mechanical | https://accu-components.com/us/left-hand-thread-hex-jam-nuts/73142-HFNL-M8-A2 | Phase 1 | 0.004
[ROLL UPGRADE qty0] Conical high-misalignment spacers M8->M6 for metal rod-ends (pair) | Competition Supplies / McGill Motorsport | €0.00 | 22% |  | 0 |  | Pair of stepped/conical bushings: cylindrical part in the Ø8 bore of the ball, narrow cone towards the lugs, M6 through bolt. The eye touches the cone instead of the wide face -> +8-12 degrees/side = ±20-25 total on standard metal rod-ends. | Low-cost alternative to the igubal CL to raise the roll of the CURRENT rod-ends: the pin goes from Ø8 shoulder to plain M6 (less cross-section, ok for ~1-2 kN). Sources: Competition Supplies 'High misalignment spacer M8 to M6' (pair, metric), McGill Motorsport pack 6/10, Midwest Control HMBZC-M8-M6 (USA). On AliExpress search for 'heim joint misalignment spacer 8mm'. Qty at CAD. | Mechanical | https://www.competitionsupplies.com/rod-ends-spherical-bearings/rod-end-bearing-accessories/high-misalignment-spacers-metric/high-misalignment-spacer-m8-to-m6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 | Phase 1
AliExpress black shoulder screw Ø8 x M6 x 45 mm - ankle gimbal pitch/roll axes | AliExpress | €2.00 | 22% |  | 2 |  | Selected shoulder screws for the ankle offset gimbal: Ø8 mm shoulder diameter, M6 thread, 45 mm shoulder length. Use two screws stacked in Z: higher screw = pitch axis, lower screw = roll axis. | FIRST CHOICE listing from user update 2026-06-27, revised after lower-leg CAD screenshot. This is intentionally an offset gimbal, so CAD/simulation must use the measured pitch-roll Z offset rather than an ideal intersecting-axis Cardan approximation. Add Loctite 243 and M6 nut/locknut as listed above. | Mechanical | https://it.aliexpress.com/item/1005007885495357.html | Phase 1
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

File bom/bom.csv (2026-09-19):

item | supplier | unit_cost_eur_net | qty | phase | mass_kg | link | description
M6 nuts for Ø8/M6 shoulder screws - ankle gimbal + pushrod pivots | Amazon / AliExpress | 0.2 | 6 | Phase 1 |  | https://www.amazon.it/Acciaio-Controdado-Esagonale-Inserto-Autobloccante/dp/B0C8ZCR6B1 | Six standard M6 nuts for the selected Ø8/M6 shoulder screws: 2 nuts for the 45 mm ankle gimbal screws and 4 nuts for the 16 mm pushrod rod-end pivot screws. Geometry to reserve in CAD: M6 hex across flats 10 mm, circumscribed hex diameter about 11.55 mm; normal M6 locknut height is about 6 mm.
AliExpress adjustable aluminum M8 pushrod - 140 mm ankle link | AliExpress | 7 | 2 | Phase 1 | 0.048 | https://it.aliexpress.com/item/1005008935554718.html | Adjustable aluminum M8 pushrod/link for the parallel/differential ankle. Selected long variant: 140 mm. CAD body mass estimate: 23.8 g each, excluding the separately listed igubal ends and M8 jam nuts.
AliExpress adjustable aluminum M8 pushrod - 40 mm ankle link | AliExpress | 7 | 2 | Phase 1 | 0.014 | https://it.aliexpress.com/item/1005008935554718.html | Adjustable aluminum M8 pushrod/link for the parallel/differential ankle. Selected short variant: 40 mm. CAD body mass estimate: 6.8 g each, excluding the separately listed igubal ends and M8 jam nuts.
igus igubal KARM-08 CL / KARM_08_CL_1 - M8 right-hand male rod end, Ø8 bore, ±35° | igus | 0 | 2 | Phase 1 | 0.012 | https://www.igus.com/product?artNr=KARM-08-CL | Selected right-hand spherical rod ends for the ankle pushrods: igus igubal KARM-08 CL, model KARM_08_CL_1, male M8 right-hand thread, Ø8 E10 ball bore for the Ø8/M6 shoulder screws, pivot angle ±35°, weight 6.2 g each.
igus igubal KALM-08 CL - M8 left-hand male rod end, Ø8 bore, ±35° | igus / ERIKS | 0 | 2 | Phase 1 | 0.012 | https://shop.eriks.de/de/waelzlager-gelenklager-und-gelenkkoepfe-gelenkkoepfe/gelenkkopf-wartungsfrei-igumid-g-iglidur-j-aussengewinde-links-serie-kalm-cl-j-p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 | Selected left-hand spherical rod ends for the ankle pushrods: igus igubal KALM-08 CL family, male M8 left-hand thread, Ø8 E10 ball bore for the Ø8/M6 shoulder screws, target pivot angle ±35° matching the KARM-08 CL geometry.
DIN 439 M8 thin jam nut, right-hand thread - pushrod length lock | Accu / Fabory | 0.5 | 2 | Phase 1 | 0.004 | https://www.accu.co.uk/thin-hexagon-nuts/73062-HFN-M8-A2 | Thin right-hand jam nuts for locking the two KARM-08 right-hand rod ends after pushrod length adjustment. Standard DIN 439 / ISO 4035 M8 x 1.25 geometry: height along thread 4.0 mm, across flats 13 mm, circumscribed hex diameter about 15.0 mm.
DIN 439 M8 thin jam nut, left-hand thread - pushrod length lock | Accu / Fabory | 0.5 | 2 | Phase 1 | 0.004 | https://accu-components.com/us/left-hand-thread-hex-jam-nuts/73142-HFNL-M8-A2 | Thin left-hand jam nuts for locking the two KALM-08 left-hand rod ends after pushrod length adjustment. Standard DIN 439 / ISO 4035 M8 x 1.25 left-hand geometry: height along thread 4.0 mm, across flats 13 mm, circumscribed hex diameter about 15.0 mm.
AliExpress black shoulder screw Ø8 x M6 x 45 mm - ankle gimbal pitch/roll axes | AliExpress | 2 | 2 | Phase 1 |  | https://it.aliexpress.com/item/1005007885495357.html | Selected shoulder screws for the ankle offset gimbal: Ø8 mm shoulder diameter, M6 thread, 45 mm shoulder length. Use two screws stacked in Z: higher screw = pitch axis, lower screw = roll axis.
AliExpress black shoulder screw Ø8 x M6 x 16 mm - pushrod rod-end pivots | AliExpress | 2 | 4 | Phase 1 |  | https://it.aliexpress.com/item/1005007885495357.html | Selected shoulder screws for the M8 pushrod rod-end pivots: Ø8 mm shoulder diameter, M6 thread, 16 mm shoulder length. The Ø8 shoulder passes through the rod-end spherical bearing.
Heat-set brass threaded inserts M3/M4/M5 | Prusa / VXB | 25 | 1 | Phase 1 |  | https://www.prusa3d.com/product/threaded-inserts-m4-short-50-pcs/ | Reusable threads for PA-CF printed parts.
M3/M4/M5 screw, nut and washer assortment | Amazon | 35 | 1 | Phase 1 |  | https://www.amazon.it/SANTOO-Acciaio-Esagonale-Assortimento-Fissaggio/dp/B07RV2SFX6 | General hardware for motors, brackets and covers.
ISO 4762 socket-head cap screw M3 x 10 mm, steel, full thread | MISUMI / Würth / RS | 0.04 | 8 | Phase 1 |  | https://it.misumi-ec.com/vona2/detail/110302217940/?HissuCode=CB3-10 | Eight installed on the two RS05 neck actuators: four per actuator. Thread length is 10 mm; the socket head is not included in this length.
ISO 4762 socket-head cap screw M3 x 15 mm, steel, full thread | MISUMI / Würth / RS | 0.05 | 184 | Phase 1 |  | https://it.misumi-ec.com/vona2/detail/110302217940/?HissuCode=CB3-15 | Installed motor fasteners: 8 per RS06 x 11 actuators plus 12 per RS00 x 8 actuators = 184 screws. Thread length is 15 mm; head excluded.
ISO 4762 socket-head cap screw M4 x 15 mm, steel, full thread | MISUMI / Würth / RS | 0.06 | 201 | Phase 1 |  | https://it.misumi-ec.com/vona2/detail/110302217940/?HissuCode=CB4-15 | Installed motor fasteners: 6 per RS06 x 11 actuators + 15 per RS04 x 6 actuators + 15 per RS03 x 3 actuators = 201 screws. Thread length is 15 mm; head excluded.
ISO 4762 socket-head cap screw M4 x 20 mm, steel, full thread | MISUMI / Würth / RS | 0.07 | 12 | Phase 1 |  | https://it.misumi-ec.com/vona2/detail/110302217940/?HissuCode=CB4-20 | Six installed on each RS05 neck actuator, two actuators total. Thread length is 20 mm; head excluded.
Loctite 243 medium-strength threadlocker | Amazon | 10 | 1 | Phase 1 |  | https://www.amazon.it/Loctite-243-Frenafiletti-resistenza-azione/dp/B003ZUXQIA | Threadlocker for screws exposed to vibration.
RobStride 04 - legs: hip pitch/roll + knee (3/leg) | Seeed / RobStride | 235 | 6 | Phase 2 | 8.716 | https://www.seeedstudio.com/Robostride-04-Actuator-p-6775.html | Axes: hip pitch/roll + knee, 3 per leg. RobStride PDF 2025-06-26 dimensions: OD 120 mm, length 56 mm. Weight: 1.420 kg. RobStride torque: 40 Nm rated, 120 Nm peak.
RobStride 03 - leg hip yaw (1/leg) | Seeed / RobStride | 214 | 2 | Phase 2 | 1.825 | https://www.seeedstudio.com/Robostride-03-Actuator-p-6774.html | Axis: hip yaw, 1 per leg. RobStride PDF 2025-06-26 dimensions: OD 98 mm, length 54.1 mm. Weight: 0.900 kg. RobStride torque: 20 Nm rated, 60 Nm peak.
RobStride 06 - ankle pushrod/differential drive A/B (2/leg) | Seeed / RobStride | 200 | 4 | Phase 2 | 2.572 | https://www.seeedstudio.com/Robostride-06-Actuator-p-6668.html | Physical ankle actuators A/B: 2 motors per leg in the shin, acting through two pushrods. Do not label them as direct pitch/roll motors in CAD: virtual pitch and roll come from geometry and the A/B mixing map. RobStride PDF 2025-06-26 dimensions: OD 88 mm, length 49 mm. Weight: 0.621 kg. RobStride torque: 11 Nm rated, 36 Nm peak.
RobStride 06 - G1 waist yaw | Seeed / RobStride | 200 | 1 | Phase 3 | 0.643 | https://www.seeedstudio.com/Robostride-06-Actuator-p-6668.html | Axis: waist yaw, vertical motor mounted above the lower waist-roll stage and rotating the torso/yaw assembly. RobStride PDF 2025-06-26 dimensions: OD 88 mm, length 49 mm. Weight: 0.621 kg. RobStride torque: 11 Nm rated, 36 Nm peak.
RobStride 03 - direct serial waist roll below yaw | Seeed / RobStride | 210 | 1 | Phase 3 | 0.913 | https://www.seeedstudio.com/Robostride-03-Actuator-p-6774.html | Axis: waist roll, direct front-back axis mounted below the yaw joint. RobStride PDF 2025-06-26 dimensions: OD 98 mm, length 54.1 mm. Weight: 0.900 kg. RobStride torque: 20 Nm rated, 60 Nm peak.
RobStride 06 - proximal shoulder pitch/roll (2/arm) - RIGHT arm | Seeed / RobStride | 200 | 2 | Phase 1 | 1.286 | https://www.seeedstudio.com/Robostride-06-Actuator-p-6668.html | Axes: proximal shoulder pitch/roll, 2 per arm. RobStride PDF 2025-06-26 dimensions: OD 88 mm, length 49 mm. Weight: 0.621 kg. RobStride torque: 11 Nm rated, 36 Nm peak.
RobStride 06 - proximal shoulder pitch/roll (2/arm) - LEFT arm | Seeed / RobStride | 200 | 2 | Phase 3 | 1.286 | https://www.seeedstudio.com/Robostride-06-Actuator-p-6668.html | Axes: proximal shoulder pitch/roll, 2 per arm. RobStride PDF 2025-06-26 dimensions: OD 88 mm, length 49 mm. Weight: 0.621 kg. RobStride torque: 11 Nm rated, 36 Nm peak.
RobStride 00 - light shoulder yaw (1/arm) - RIGHT arm | Seeed / RobStride | 116 | 1 | Phase 1 | 0.323 | https://www.seeedstudio.com/Robostride-00-Actuator-p-6664.html | Axis: shoulder yaw, the most distal shoulder axis. RobStride PDF 2025-06-26 dimensions: OD 57 mm, length 51 mm. Weight: 0.310 kg. RobStride torque: 5 Nm rated, 14 Nm peak.
RobStride 00 - light shoulder yaw (1/arm) - LEFT arm | Seeed / RobStride | 116 | 1 | Phase 3 | 0.323 | https://www.seeedstudio.com/Robostride-00-Actuator-p-6664.html | Axis: shoulder yaw, the most distal shoulder axis. RobStride PDF 2025-06-26 dimensions: OD 57 mm, length 51 mm. Weight: 0.310 kg. RobStride torque: 5 Nm rated, 14 Nm peak.
RobStride 06 - elbow (1/arm) - RIGHT arm | Seeed / RobStride | 200 | 1 | Phase 1 | 0.643 | https://www.seeedstudio.com/Robostride-06-Actuator-p-6668.html | Axis: elbow, 1 per arm. RobStride PDF 2025-06-26 dimensions: OD 88 mm, length 49 mm. Weight: 0.621 kg. RobStride torque: 11 Nm rated, 36 Nm peak.
RobStride 06 - elbow (1/arm) - LEFT arm | Seeed / RobStride | 200 | 1 | Phase 3 | 0.643 | https://www.seeedstudio.com/Robostride-06-Actuator-p-6668.html | Axis: elbow, 1 per arm. RobStride PDF 2025-06-26 dimensions: OD 88 mm, length 49 mm. Weight: 0.621 kg. RobStride torque: 11 Nm rated, 36 Nm peak.
RobStride 00 - uniform 3-axis wrist: roll (1/arm) - RIGHT arm | Seeed / RobStride | 116 | 1 | Phase 1 | 0.323 | https://www.seeedstudio.com/Robostride-00-Actuator-p-6664.html | Axis: wrist roll, 1 per arm. RobStride PDF 2025-06-26 dimensions: OD 57 mm, length 51 mm. Weight: 0.310 kg. RobStride torque: 5 Nm rated, 14 Nm peak.
RobStride 00 - uniform 3-axis wrist: roll (1/arm) - LEFT arm | Seeed / RobStride | 116 | 1 | Phase 3 | 0.323 | https://www.seeedstudio.com/Robostride-00-Actuator-p-6664.html | Axis: wrist roll, 1 per arm. RobStride PDF 2025-06-26 dimensions: OD 57 mm, length 51 mm. Weight: 0.310 kg. RobStride torque: 5 Nm rated, 14 Nm peak.
RobStride 00 - uniform 3-axis wrist: pitch/yaw (2/arm) - RIGHT arm | Seeed / RobStride | 116 | 2 | Phase 1 | 0.647 | https://www.seeedstudio.com/Robostride-00-Actuator-p-6664.html | Axes: wrist pitch/yaw, 2 per arm. RobStride PDF 2025-06-26 dimensions: OD 57 mm, length 51 mm. Weight: 0.310 kg. RobStride torque: 5 Nm rated, 14 Nm peak.
RobStride 00 - uniform 3-axis wrist: pitch/yaw (2/arm) - LEFT arm | Seeed / RobStride | 116 | 2 | Phase 3 | 0.647 | https://www.seeedstudio.com/Robostride-00-Actuator-p-6664.html | Axes: wrist pitch/yaw, 2 per arm. RobStride PDF 2025-06-26 dimensions: OD 57 mm, length 51 mm. Weight: 0.310 kg. RobStride torque: 5 Nm rated, 14 Nm peak.
RobStride 05 - G1-Comp neck pan/tilt (2 axes) | Seeed / RobStride | 100 | 2 | Phase 3 | 0.423 | https://www.seeedstudio.com/Robostride-05-Actuator-p-6666.html | Axes: G1-Comp neck pan/tilt. RobStride PDF 2025-06-26 dimensions: OD 46 mm, length 44 mm. Weight: 0.191 kg. RobStride torque: 1.6 Nm rated, 5.5 Nm peak.
Inspire Robots RH56DFX-2L dexterous hand, left, without wrist | Reichelt Italia - ALREADY OWNED (lab) | 0 | 1 | Phase 3 | 0.54 | https://www.reichelt.com/it/it/shop/prodotto/rh56dfx_-_mano_robotica_destreggiata_senza_polso_sinistra-426921 | Left six-actuator dexterous hand without the Inspire wrist module. Six actuated DOF, 12 moving joints, 24 V supply, RS485 communication, 217.8 mm overall length, about 80.7 mm palm width and 0.540 kg mass.
Inspire Robots RH56DFX-2R dexterous hand, right, without wrist | Reichelt Italia - ALREADY OWNED (lab) | 0 | 1 | Phase 1 | 0.54 | https://www.reichelt.com/it/it/shop/prodotto/rh56dfx_-_mano_robotica_destreggiata_senza_polso_destra-426913 | Right six-actuator dexterous hand without the Inspire wrist module. Six actuated DOF, 12 moving joints, 24 V supply, RS485 communication, 217.8 mm overall length, about 80.7 mm palm width and 0.540 kg mass.
MEAN WELL RSP-3000-48 bench supply (48 V, 3000 W) | DigiKey | 511.5 | 1 | Phase 1 |  | https://www.digikey.com/en/products/detail/mean-well-usa-inc/RSP-3000-48/7706324 | Bench AC/DC supply: 230 VAC input to 48 VDC motor bus, up to 62.5 A / 3000 W. Size 278 x 177.8 x 63.5 mm, weight about 4.0 kg. Not carried onboard.
Schuko mains cable -> free ends, H07RN-F 3G1.5, 3 m, IP44 | Amazon (generic) | 8.2 | 1 | Phase 1 |  | https://www.amazon.it/s?k=cavo+H07RN-F+3G1.5+spina+schuko | Mains cable for the Mean Well AC input terminals: line, neutral and protective earth. Do not use an IEC C13 cord for this supply.
Schneider XB4BS8442 - red 40 mm emergency stop, twist release, 1NC | RS Italia | 31.04 | 1 | Phase 1 | 0.07 | https://it.rs-online.com/web/p/pulsanti-di-arresto-di-emergenza/7951306 | Manual emergency-stop button. Its normally-closed contact drives the contactor coil circuit; pressing it drops the contactor and removes 48 V from the motors.
TE Connectivity KILOVAC LEV100A5ANG - 100 A main DC contactor, 24 V coil | DigiKey / Mouser / Farnell | 150.93 | 1 | Phase 1 | 0.19 | https://www.digikey.it/it/products/detail/te-connectivity-aerospace-defense-and-marine/LEV100A5ANG/2362833 | Only onboard high-current disconnect. The normally-open contactor removes battery power from all RobStride motor branches when the hardware e-stop opens its 24 V coil circuit. Body diameter 39.5 mm, mounting-flange width 46.3 mm, total height 57.96 mm; mass 0.190 kg.
Littelfuse BF1 142.5631.5702 - main fuse 70A 58VDC M5 for compact P45B battery | DigiKey | 4.3 | 1 | Phase 1 | 0.01 | https://www.digikey.com/en/products/detail/littelfuse-inc/142-5631-5702/2515910 | Main slow-blow fuse on the positive line, as close as practical to the 48 V source. Protects the 25 mm2 trunk and is a more credible baseline for the selected compact 45 A continuous / 100 A maximum BMS pack than the previous 125 A fuse.
Littelfuse 04980921GXM5 - inline MIDI/BF1 fuse holder, 58 VDC, with cover - main + right arm | Mouser | 8 | 2 | Phase 1 | 0.06 | https://www.mouser.com/ProductDetail/Littelfuse/04980921GXM5?qs=aOs975IaWlkzQw1Up%2FmjHQ%3D%3D | Insulated inline fuse holder with cover and M5 hardware for the main fuse and branch fuses.
Littelfuse 04980921GXM5 - inline MIDI/BF1 fuse holder, 58 VDC, with cover - legs | Mouser | 8 | 2 | Phase 2 | 0.06 | https://www.mouser.com/ProductDetail/Littelfuse/04980921GXM5?qs=aOs975IaWlkzQw1Up%2FmjHQ%3D%3D | Insulated inline fuse holder with cover and M5 hardware for the main fuse and branch fuses.
Littelfuse 04980921GXM5 - inline MIDI/BF1 fuse holder, 58 VDC, with cover - waist + left arm | Mouser | 8 | 2 | Phase 3 | 0.06 | https://www.mouser.com/ProductDetail/Littelfuse/04980921GXM5?qs=aOs975IaWlkzQw1Up%2FmjHQ%3D%3D | Insulated inline fuse holder with cover and M5 hardware for the main fuse and branch fuses.
Vishay Dale RHA050100R0FE02 - chassis precharge resistor, 100 ohm, 50 W | DigiKey | 8.75 | 1 | Phase 1 | 0.05 | https://www.digikey.com/en/products/detail/vishay-dale/RHA050100R0FE02/15191925 | Panel-mounted precharge resistor. It charges the distributed DC-link capacitance of the 30 actuators and harness before the main contactor closes, reducing inrush current and arcing.
CIT Relay A2K1CSQ24VDC1.6 - compact precharge relay, 24 V coil | DigiKey | 6.1 | 1 | Phase 1 | 0.04 | https://www.digikey.com/en/products/detail/cit-relay-and-switch/A2K1CSQ24VDC1-6/16687908 | Precharge-branch relay: on enable it connects the 100 ohm resistor across the main contactor. After the measured bus reaches the required voltage, the LEV100 closes and bypasses the resistor.
[DESIGN DELIVERABLE - NOT A PURCHASE] SEQ-PWR-01 safety-chain and precharge wiring drawing | Project electrical documentation | 0 | 1 | Phase 1 |  | https://www.digikey.it/it/products/detail/te-connectivity-aerospace-defense-and-marine/LEV100A5ANG/2362833 | Hardware sequencing selected 2026-07-17, no custom PCB: 24 V safety fuse -> latching e-stop NC -> START button with CIT seal-in latch relay -> precharge CIT relay + H3YN-2 on-delay timer -> timer contact -> LEV100 coil. Pressing START begins precharge and the delay; the timer closes the LEV100 on an already-charged bus; releasing the e-stop never restarts the bus, only START does. The deliverable is the released wiring drawing: terminals, wire gauges and colours, TVS placement at all three coils, mounting of latch relay, timer socket and button, and the frozen timer setting.
Schneider XB5AA31 - green 22 mm flush START pushbutton, momentary, 1NO | Schneider / RS / distributors | 15 | 1 | Phase 1 | 0.03 | https://www.se.com/ww/en/product/XB5AA31/ | Manual START command of the motor-bus power-up sequence, mounted on the outer shell next to the e-stop. Pressing it energizes the seal-in latch, which starts precharge and the on-delay timer. Panel hole diameter 22 mm; same XB5 family as the selected e-stop.
CIT Relay A2K1CSQ24VDC1.6 - START seal-in latch relay, 24 V coil | DigiKey | 6.1 | 1 | Phase 1 | 0.04 | https://www.digikey.com/en/products/detail/cit-relay-and-switch/A2K1CSQ24VDC1-6/16687908 | Second unit of the same exact relay used for precharge, wired as a seal-in latch: START energizes the coil, one contact holds it in through the e-stop chain, and the latched node feeds the precharge relay coil and the timer. E-stop or loss of 24 V drops the latch, and the bus stays down until START is pressed again.
Omron H3YN-2 DC24 - miniature multifunction on-delay timer relay, 24 VDC | DigiKey / Mouser / RS | 40 | 1 | Phase 1 | 0.05 | https://www.digikey.com/en/products/result?keywords=H3YN-2%20DC24 | Brand-name on-delay element of the precharge sequence: powered from the latched node, it closes the LEV100 coil circuit only after the set delay, so the main contactor always closes on a precharged bus. Miniature MY-relay footprint, plugs into the PYF08A-E socket below; body about 21.5 x 28 x 42 mm plus socket.
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

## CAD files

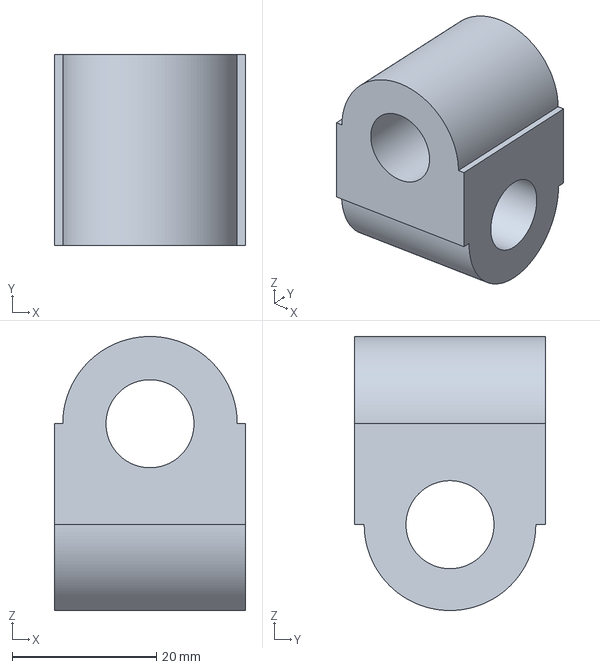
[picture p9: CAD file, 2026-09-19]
cad/3mf/ankle-gimbal.3mf
26.5 x 26.5 x 38.0 mm

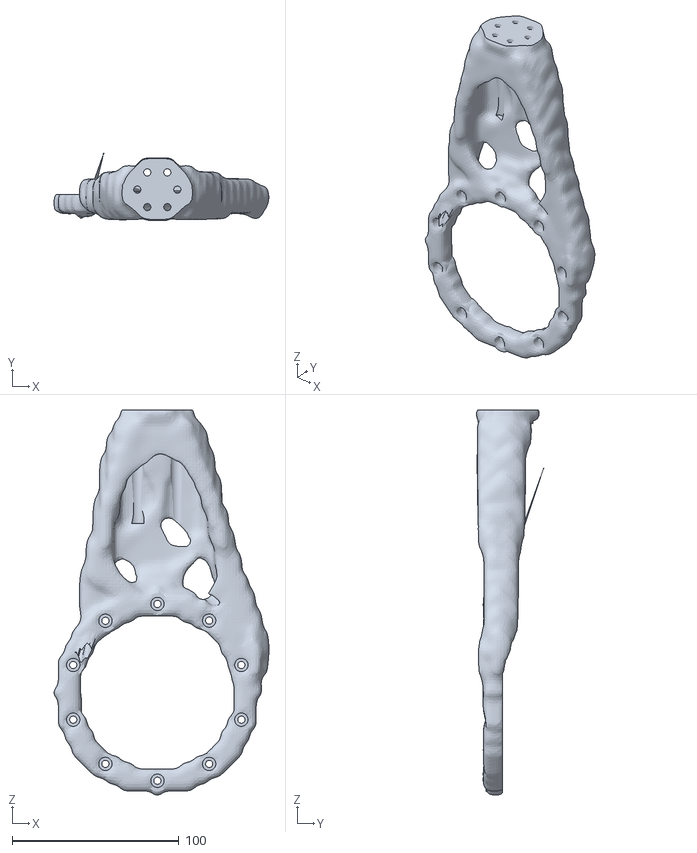
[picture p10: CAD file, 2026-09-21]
cad/bonegen/results/thigh_free_p4/final.stl
128.8 x 40.2 x 230.9

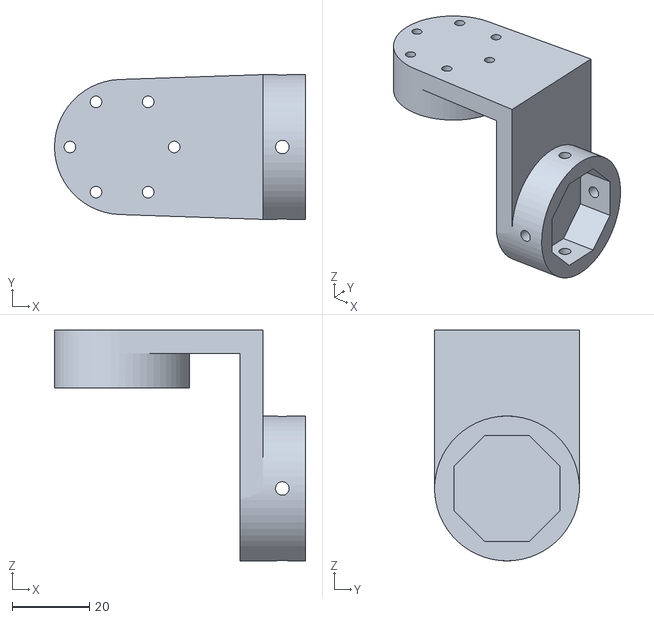
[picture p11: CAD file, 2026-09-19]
cad/stl/wrist_right.stl
65.0 x 37.5 x 59.8

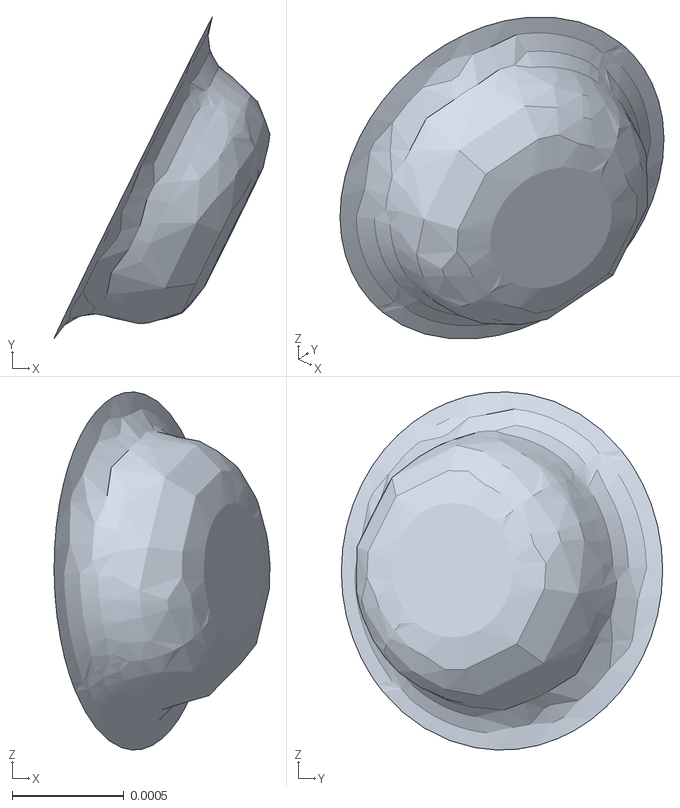
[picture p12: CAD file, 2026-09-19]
sim/meshes/__23_mirror.stl
0.000964 x 0.00144 x 0.0016

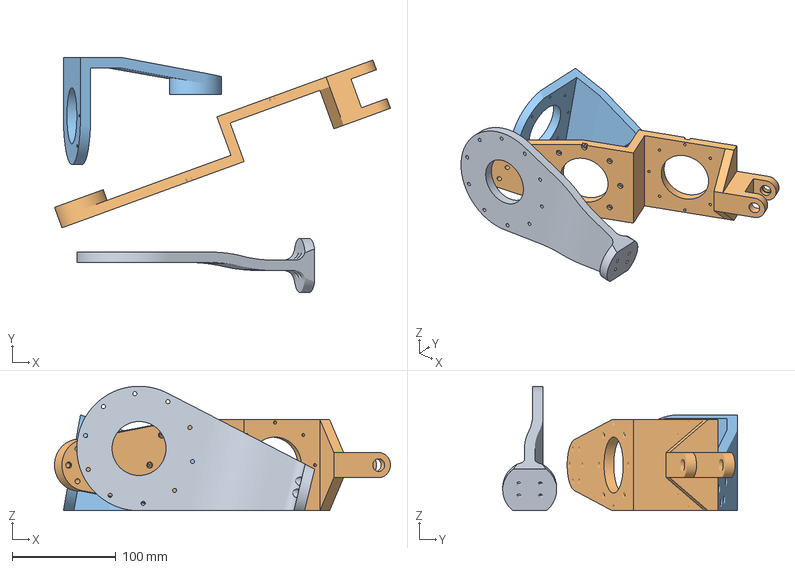
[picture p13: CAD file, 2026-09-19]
cad/3mf/leg-test-plate.3mf
324.0 x 226.2 x 120.0 mm
Part 39_femur.stl
Part 18_tibia.stl
Part 40_hip_roll_to_yaw.stl

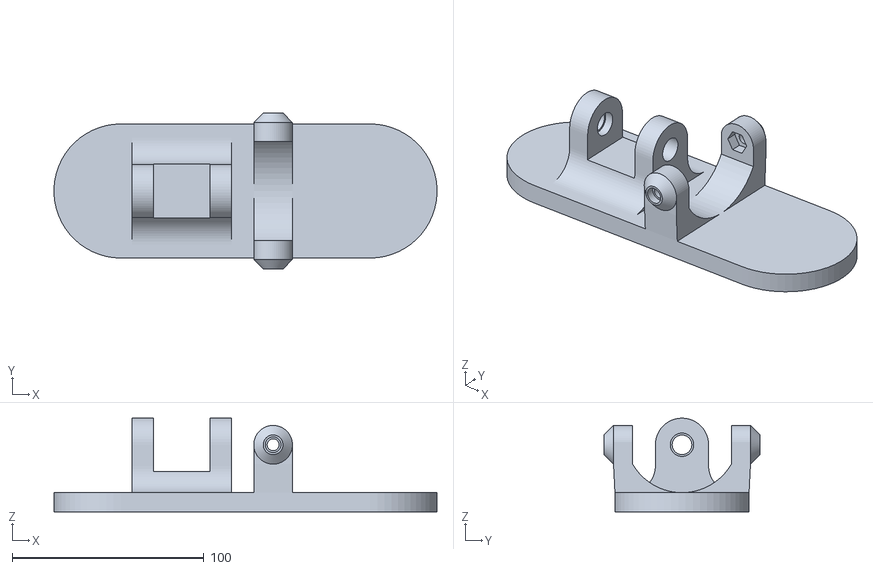
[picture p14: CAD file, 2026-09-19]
cad/stl/foot_right.stl
199.9 x 81.5 x 48.9

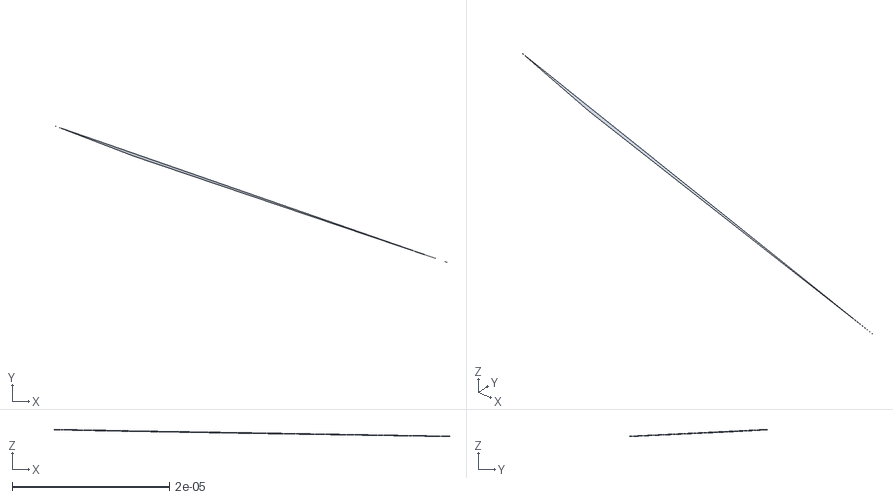
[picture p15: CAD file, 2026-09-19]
sim/meshes/__15.stl
5.03e-05 x 1.75e-05 x 8.64e-07

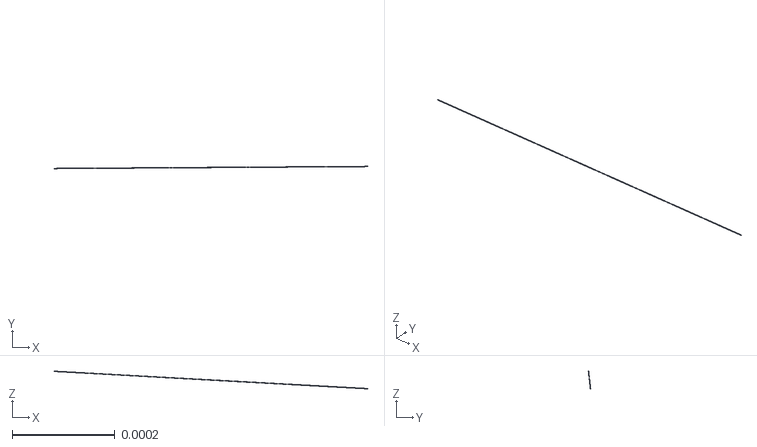
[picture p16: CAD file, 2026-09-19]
sim/meshes/__68.stl
0.000612 x 3.97e-06 x 3.39e-05

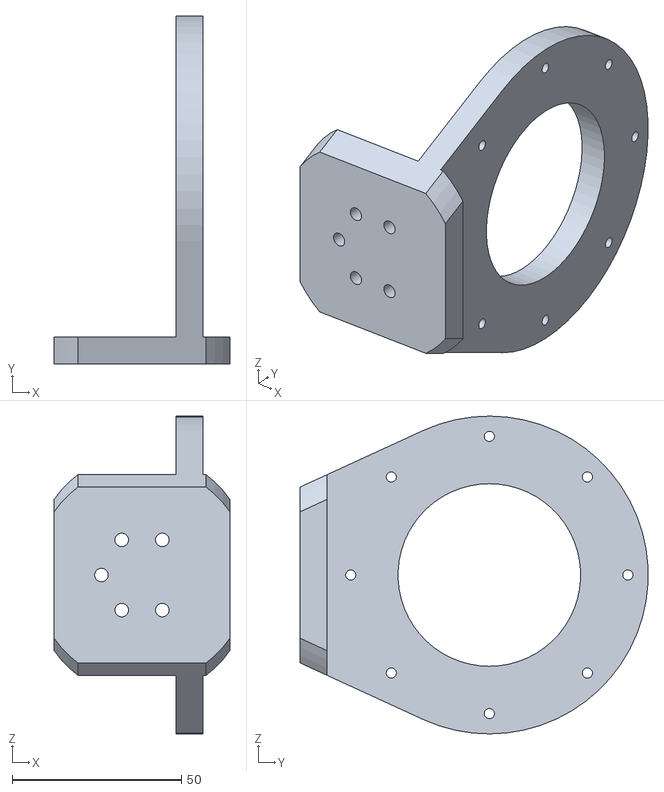
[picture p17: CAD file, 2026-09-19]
cad/stl/shoulder_pitch_to_roll_left.stl
52.0 x 102.9 x 94.0

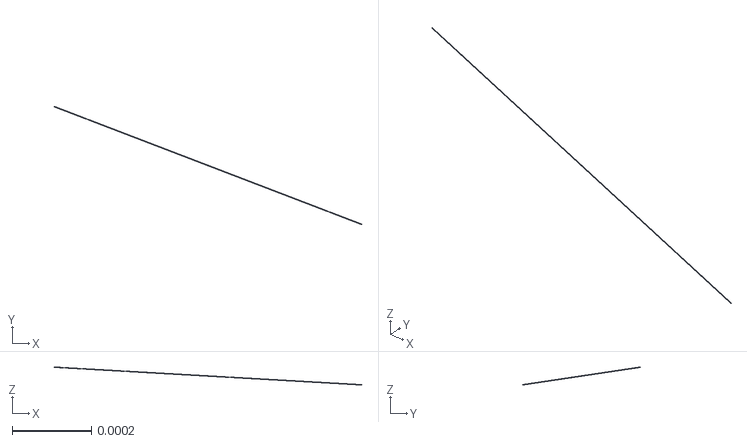
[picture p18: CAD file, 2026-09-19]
sim/meshes/__16.stl
0.000774 x 0.000296 x 4.45e-05

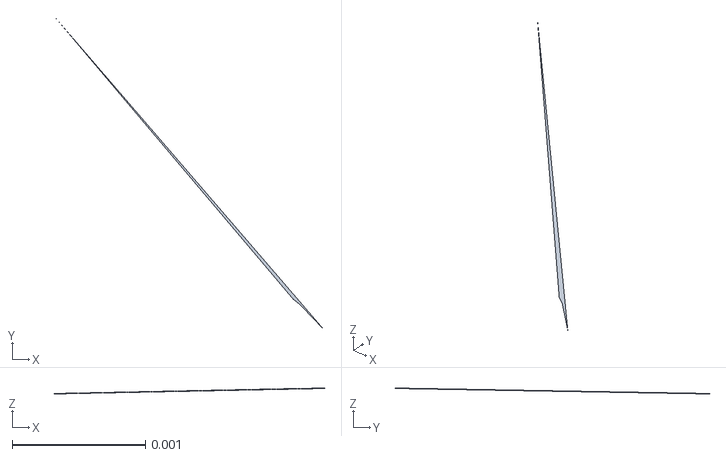
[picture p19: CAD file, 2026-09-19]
sim/meshes/__56_mirror.stl
0.00203 x 0.00235 x 4.11e-05

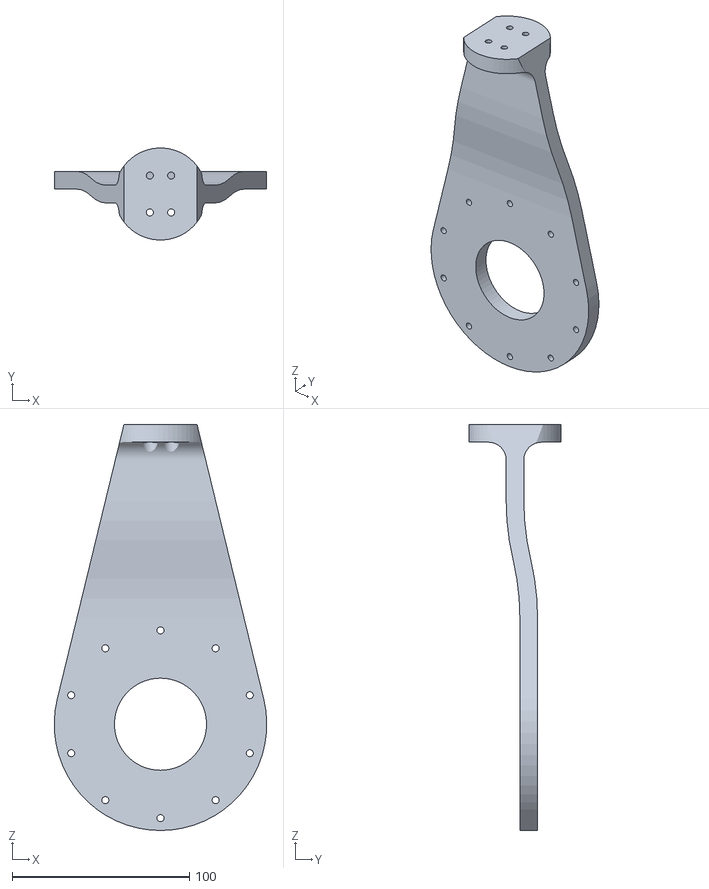
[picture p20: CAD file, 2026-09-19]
cad/stl/femur_left.stl
120.0 x 51.9 x 229.2

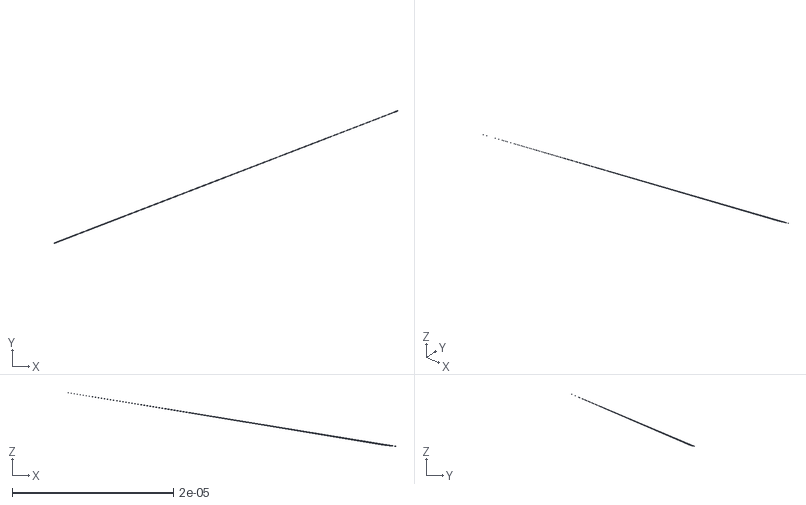
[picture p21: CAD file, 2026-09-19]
sim/meshes/__52_mirror.stl
4.25e-05 x 1.64e-05 x 6.94e-06

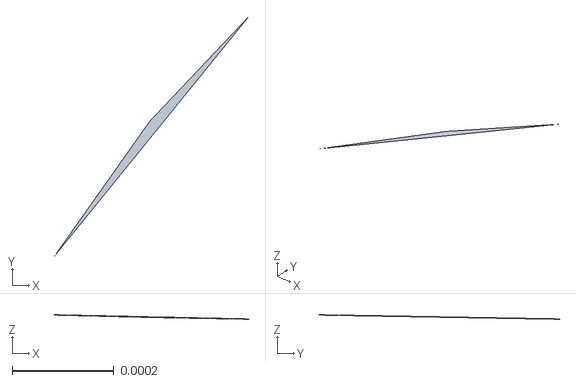
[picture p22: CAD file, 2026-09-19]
sim/meshes/__14_mirror.stl
0.000382 x 0.000471 x 8.23e-06

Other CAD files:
cad/stl/ankle_gimbal_left.stl
cad/stl/ankle_gimbal_right.stl
cad/stl/femur_right.stl
cad/stl/foot_left.stl
cad/stl/ankle_crank_lower_left.stl
cad/stl/ankle_crank_lower_right.stl
cad/stl/ankle_crank_upper_left.stl
cad/stl/ankle_crank_upper_right.stl
cad/stl/elbow_left.stl
cad/stl/elbow_pitch_to_forearm_roll_left.stl
cad/stl/elbow_pitch_to_forearm_roll_right.stl
cad/stl/elbow_right.stl
cad/stl/forearm_pitch_to_yaw_left.stl
cad/stl/forearm_pitch_to_yaw_right.stl
cad/stl/forearm_roll_to_pitch_left.stl
cad/stl/forearm_roll_to_pitch_right.stl
cad/stl/head.stl
cad/stl/hip_pitch_to_roll_left.stl
cad/stl/hip_pitch_to_roll_right.stl
cad/stl/hip_roll_to_yaw_left.stl
cad/stl/hip_roll_to_yaw_right.stl
cad/stl/neck_yaw_to_pitch.stl
cad/stl/pelvis.stl
cad/stl/ribcage.stl
cad/stl/shoulder_pitch_to_roll_right.stl
cad/stl/shoulder_roll_to_yaw_left.stl
cad/stl/shoulder_roll_to_yaw_right.stl
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

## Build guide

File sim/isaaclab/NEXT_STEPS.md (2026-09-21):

# Next steps, with the traps already mapped

Concrete guidance for the work that follows, written while the context is fresh.

---

## 1. Hip-yaw torque gate — do this first, it blocks a purchase

The CAD uses RobStride **RS06 (36 Nm peak)** at hip yaw; the locked BOM specifies **RS03 (60 Nm)**.
The decision was deliberately deferred to measurement.

**Method** — during turning (nonzero `ang_vel_z` commands), log
`env.scene["robot"].data.applied_torque[:, hip_yaw_ids]` across a long rollout. Report peak, RMS,
95th/99th percentile, and the fraction of samples above 80/90/95/99% of the 36 Nm limit. If it
saturates for more than about 2-5% of steps at the target turn rates, RS03 is required.

`knee_probe.py` is the template — it already patches `play.py`'s `env.step` to sample robot state
during a rollout; swap the knee angles for `applied_torque` and the same structure works.

**Two cautions**:
- Compare against the **rated** (continuous) torque, not just peak. RS04 is 120 Nm peak but only
  40 Nm rated, and continuous rating is where a real motor overheats.
- The ankle is a 2x RS06 pushrod differential modelled as two virtual joints. Simulated virtual
  joint torque is **not** the torque of either physical motor — it must be mapped through the real
  linkage Jacobian before any ankle motor conclusion.

---

## 2. Adding pushes

Worth knowing before you start: **H1, G1 and Cassie all disable push randomisation** in their
official Isaac Lab configs (`self.events.push_robot = None`). Only Digit keeps it. Our own attempt
at a faithful Digit port — with pushes on and backward/lateral commands — stalled at ~18 episode
length from a cold start, and only worked once pushes were turned off.

**Recommendation**: do not train from scratch with pushes. Fine-tune the working KneeHard policy
with pushes introduced gradually. Unlike gait *shape* (which fine-tuning cannot fix — see
HANDOFF round 1.75), robustness is exactly the kind of thing fine-tuning does well.

```python
self.events.push_robot = EventTerm(
    func=mdp.push_by_setting_velocity,
    mode="interval",
    interval_range_s=(10.0, 15.0),                       # start sparse
    params={"velocity_range": {"x": (-0.3, 0.3), "y": (-0.3, 0.3)}},   # start small
)
```

Then ramp magnitude and frequency over successive fine-tunes. Check after each stage that knee
flexion has not collapsed back (`knee_probe.py`) — push recovery is a plausible reason for a
policy to re-discover stiff legs.

While you are there, the other domain randomisation worth adding before sim-to-real: base mass
(`add_base_mass`), CoM offset, ground friction, motor strength scaling, action latency, and
IMU/joint-observation noise. Introduce them one at a time, not as a block.

---

## 3. Unlocking more joints

Current action space is 12 leg joints + waist roll. Natural next additions, in order of value:

1. **Waist yaw** — helps turning, low risk.
2. **Shoulder pitch + roll** — arm swing. The single biggest visual gain toward natural walking.
3. **Elbows** — optional, small additional benefit.

Keep wrists, shoulder yaw and neck held.

**Three specific traps**:

- **`events.hold_default_joint_targets` must stay** for whatever remains outside the action space.
  Without it those joints drive to the URDF zero pose, not your configured pose. This silently
  affected every legs-only run for several rounds (LESSONS.md B2).
- **The arms have no collision geometry** in the current URDF export. Before enabling arm swing,
  add collision to the arm links — otherwise the policy can swing an arm through the torso and
  learn a gait that is impossible on hardware.
- **Changing the action dimension invalidates the policy head.** You cannot fine-tune KneeHard
  into a larger action space; that is a retrain. So decide the final action set *before* investing
  in a long curriculum.

A 15-degree outward shoulder-roll offset is already in the default pose specifically so the arms
clear the hips when the waist rolls. Keep it when arms become active, or re-check hip clearance.

---

## 4. The conservative "walk mode" (unfinished)

The goal — a precise, small-step mode for positioning, like the walk/run switch on a G1 remote —
is still open. Round 3 attempted it and failed: cutting the swing incentive and adding stand-still
bonuses made standing the reward optimum, so the robot simply stopped walking.

**Better approach**: keep the working KneeHard reward set unchanged and constrain only the
*command distribution* — train (or fine-tune) with a low-speed command range and a small nonzero
floor, so slow walking is required rather than standing being rewarded. Alternatively train one
policy on the full speed range and expose speed as the mode switch at deploy time, which is closer
to what the G1 remote actually does.

Whatever you try, judge it against the round-3 failure mode: check the robot still *moves* when
commanded slowly, rather than scoring well by standing still.

---

## 5. Standing discipline for the whole project

The two habits that would have saved the most time:

1. **Change one variable per run, and always keep an unchanged control in the batch.**
2. **Measure the property you are judging.** Build the probe before the second argument about what
   a video shows. `knee_probe.py` took ten minutes to write and settled a question that had
   consumed two rounds.

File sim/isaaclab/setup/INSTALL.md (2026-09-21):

# Setup and reproduction

## Environment

| Component | Version | Note |
|---|---|---|
| Python | 3.11 | Isaac Sim 5.1 requires it |
| Isaac Sim | 5.1.0 | `pip install "isaacsim[all,extscache]==5.1.0" --extra-index-url https://pypi.nvidia.com` |
| Isaac Lab | 2.3.2 | source checkout, editable install (`isaaclab.bat --install`) |
| PyTorch | 2.7.0+cu128 | pinned by `isaacsim-core` |
| **tensordict** | **0.8.3** | **pin required** — 0.13 crashes inside Kit (`_C.pyd` access violation) |
| **NVIDIA driver** | **580.88** | **pin required** on Blackwell — 595.x crashes the RTX renderer |
| RSL-RL | as shipped with Isaac Lab 2.3.2 | |

GPU used: RTX PRO 6000 Blackwell (96 GB). Six concurrent runs at 1024 envs draw about 26 GB,
126 W, 63 C — comfortable. Do not stack other heavy training on top; the machine hard-reset once
when a VLA training job was added.

## Where the files go

The task package is an Isaac Lab extension, so the files must sit inside the Isaac Lab source tree:

```
code/assets/robstride.py
code/assets/project_humanoid.py
        -> source/isaaclab_assets/isaaclab_assets/robots/
           then add `from .robstride import *` to robots/__init__.py

code/tasks/*.py
code/tasks/agents/*.py
        -> source/isaaclab_tasks/isaaclab_tasks/manager_based/locomotion/velocity/config/robstride/

code/symmetry/humanoid_biped.py
        -> source/isaaclab_tasks/isaaclab_tasks/manager_based/locomotion/velocity/mdp/symmetry/
           then add `from . import humanoid_biped` to symmetry/__init__.py

code/scripts/*
        -> anywhere; they take absolute paths
```

**Edit one path**: `ROBSTRIDE_USD_PATH` at the top of `robstride.py` points at the converted robot
USD. Change it to wherever your `rl_full.usd` lives.

## Building the robot USD from the URDF

```bash
isaaclab.bat -p scripts/tools/convert_urdf.py \
    /path/to/rl_full.urdf /path/to/out/rl_full.usd --merge-joints --headless
```

Before converting, apply the foot-collision fix (full-mesh foot collision is both unstable and
geometrically wrong — see LESSONS.md C1):

```bash
python code/scripts/simplify_foot_collision.py     # rewrites the two foot links to a sole-plate box
python code/scripts/audit_collisions.py            # reports box-vs-mesh fidelity for every body
```

Merged body names the configs depend on: root = `root`, torso = `waist_yaw_link`,
feet = `left/right_ankle_roll_link`.

## Standard run command

Every element of this matters — see LESSONS.md section D:

```
cmd /c "set OMNI_KIT_ACCEPT_EULA=YES&& set OMNI_CRASHREPORTER_ENABLED=0&& set PYTHONUNBUFFERED=1&& ^
  call <venv>\Scripts\activate.bat && cd /d <IsaacLab> && ^
  call <IsaacLab>\isaaclab.bat -p <script> [--headless] > <UNIQUE_log_file> 2>&1"
```

- full path to `isaaclab.bat` (a bare name fails after `cd` in cmd)
- `PYTHONUNBUFFERED=1` or your diagnostics disappear
- `OMNI_CRASHREPORTER_ENABLED=0` or crash-dump uploads stall startup
- a **unique log file per launch** — reusing one wedges the process

For multiple runs use `code/scripts/launch_sequential.ps1`: it launches one, waits for its first
`Learning iteration` line, then launches the next. Fixed staggers are not reliable.

## Task IDs

The chosen policy:

- `Isaac-Velocity-R5-KneeHard-v0` / `-Play-v0`

Other registered families (all the experiments described in HANDOFF.md):

| family | variants |
|---|---|
| `Isaac-Velocity-{Flat,Rough}-Robstride-v0` | original baselines |
| `Isaac-Velocity-Way-<X>-v0` | G1, TienKung, Digit, H1, Cassie, Hybrid |
| `Isaac-Velocity-Soft-<X>-v0` | Soft, SoftImpact, SoftSlow, SoftTiny, SoftClock, SoftPend |
| `Isaac-Velocity-R3-<X>-v0` | WalkG1, WalkH1, WalkTiny, RunPend, RunImpact, RunG1 |
| `Isaac-Velocity-R4-<X>-v0` | PendBase, PendShort, PendLow, PendSlow, ImpactShort, PendTrack |
| `Isaac-Velocity-R5-<X>-v0` | ArmsFwd, KneeSoft, **KneeHard**, Crouch, KneeDefault, KneeTorque |

## Train, play, measure

```bash
# train the chosen recipe
isaaclab.bat -p scripts/reinforcement_learning/rsl_rl/train.py \
    --task Isaac-Velocity-R5-KneeHard-v0 --num_envs 1024 --headless

# play a checkpoint (NOTE: full path, unlike train.py)
isaaclab.bat -p scripts/reinforcement_learning/rsl_rl/play.py \
    --task Isaac-Velocity-R5-KneeHard-Play-v0 --num_envs 4 \
    --video --video_length 1000 --headless \
    --checkpoint /abs/path/kneehard_model_2999.pt

# measure knee flexion (the check that should gate every reward change)
isaaclab.bat -p code/scripts/knee_probe.py \
    --task Isaac-Velocity-R5-KneeHard-Play-v0 \
    --checkpoint /abs/path/kneehard_model_2999.pt --headless

# confirm symmetry augmentation is really active (it can silently no-op)
isaaclab.bat -p code/scripts/verify_symmetry.py --headless
```

When copying a recorded video, poll the file size until it stops changing — ffmpeg finishes
writing after `play.py` returns.

## Other tools

| script | what it answers |
|---|---|
| `knee_probe.py` | Do the knees actually bend? (mean angle, % time straight) |
| `verify_symmetry.py` | Is the symmetry augmentation really mirroring, or silently no-op? |
| `foot_zero_check.py` | Is the URDF mirror exact? (FK root to both feet at zero pose) |
| `audit_collisions.py` | How well does each collision primitive match its mesh? |
| `simplify_foot_collision.py` | Rewrite foot collision to the true sole plate |
| `preview_pose.py` | Render a joint pose from two angles (sweep several values at once) |
| `joint_jog.py` | Interactive GUI slider per joint, robot fixed in space |
| `stand_test.py` | Hold the default pose and report height/tilt (see LESSONS.md B5 for its limits) |
| `launch_sequential.ps1` | Launch several runs safely |
| `probe_all.ps1` / `record_r4.ps1` | Batch measurement / batch video recording |

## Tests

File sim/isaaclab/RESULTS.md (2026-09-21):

# Measured results

All runs: RSL-RL PPO, 3000 iterations unless noted, 1024-2048 parallel envs, RTX PRO 6000 Blackwell.
"Episode length" is mean steps survived out of 1000. "% straight" is the fraction of time a knee is
flexed less than 5.7 degrees, from `knee_probe.py` over a 500-step rollout.

---

## Round 1 — flat terrain, whole body (28 actions)

| recipe | episode length | velocity error | gait by eye |
|---|---|---|---|
| G1-style | 983 | 0.03 | survives, visibly lame |
| TienKung-style (gait clock) | 1000 | 0.43 | survives, poor tracking |
| legs-only baseline | ~900 | - | hopping |

Conclusion: survival metrics saturate and stop discriminating. Gait quality must be judged
separately.

---

## Round 1.5 — the `base_height` termination bug

Same trained flat policy, evaluated/fine-tuned on rough terrain:

| condition | episode length |
|---|---|
| rough, `base_height` termination active | **1.23** |
| rough, termination removed (same policy, same checkpoint) | 11 → 43 → 96 → 142 → 479 → **872** |

A single flat-terrain-only termination had been invalidating every rough-terrain experiment.

---

## Round 2a — six-way reward bake-off (rough terrain, symmetry on)

Final episode lengths after 3000 iterations:

| recipe | episode length |
|---|---|
| Cassie (minimal reward set) | 908 |
| Hybrid | 908 |
| H1 | 890 |
| G1 | 881 |
| TienKung | 841 |
| Digit | 828 |

Trajectory note — early readings are misleading:

| recipe | iter ~250 | iter ~700 | final |
|---|---|---|---|
| G1 | 908 | 881 | 881 |
| Hybrid | 178 | ~850 | 908 |
| Digit | 66 | 828 | 828 |

Hybrid and Digit both looked broken early and finished at the top of the field.

---

## Round 2b — soft-landing variants (rough terrain)

First attempt, penalties at constraint strength — all six stalled:

| iteration | episode length (all six) |
|---|---|
| 250 | 50-60 |
| 400 | 63-78 |

After halving every new penalty weight:

| recipe | episode length | velocity error |
|---|---|---|
| SoftTiny | 946 | 0.457 |
| SoftImpact | 945 | 0.399 |
| Soft | 909 | 0.519 |
| SoftPend | 902 | **0.398** |
| SoftSlow | 885 | 0.423 |
| SoftClock (gait clock) | **86** | - (killed) |

User verdict: SoftPend and SoftImpact good, steps too big. SoftClock confirms the gait clock fails.

---

## Round 3 — WALK/RUN split (regression)

| recipe | terrain | episode length | gait by eye |
|---|---|---|---|
| WalkG1 | flat | 1000 | **stands still** |
| WalkH1 | flat | 993 | **stands still** |
| WalkTiny | flat | 999 | **stands still** |
| RunPend | rough | 861 | walks, **locked knees** |
| RunImpact | rough | 879 | walks, **locked knees** |
| RunG1 | rough | 864 | walks, **locked knees** |

Perfect episode lengths, unusable policies. The walks found standing as the reward optimum after
the swing incentive was cut to a quarter and stand-still bonuses were added.

---

## Round 5 — knee flexion, measured

`knee_probe.py`, 500-step rollout, 32 envs, model_2999 of each run:

| variant | mean knee | range | % straight | pelvis above feet | verdict |
|---|---|---|---|---|---|
| PendBase (round-4 ref) | -3.6 deg | -5.4 … 137.0 | 96.1% | 0.728 m | locked |
| ArmsFwd (hypothesis test) | -4.4 deg | -5.4 … 130.8 | 98.3% | 0.730 m | locked |
| KneeSoft (-0.5, min 0.15) | -3.0 deg | -5.4 … 165.0 | 95.6% | 0.725 m | no effect |
| Crouch (pelvis cap 0.70) | -3.3 deg | -5.4 … 165.0 | 94.5% | 0.729 m | no effect |
| KneeDefault (bent default) | 26.4 deg | -5.2 … 103.3 | 0.1% | 0.721 m | works |
| KneeTorque (-1.0 + no knee torque tax) | 35.1 deg | -5.2 … 130.5 | 0.9% | 0.702 m | works |
| **KneeHard (-2.0, min 0.25)** | **36.1 deg** | **-5.2 … 116.0** | **0.4%** | **0.700 m** | **chosen** |

Two independent readings of the same conclusion: the arm pose is irrelevant to knee flexion
(ArmsFwd is the *most* locked variant), and removing the knee torque tax alone fixes it
(KneeTorque), which identifies the torque penalty as the mechanism that made locking optimal.

---

## Chosen policy

`policy/kneehard_model_2999.pt`

- Task: `Isaac-Velocity-R5-KneeHard-v0`, rough terrain with 5-23 cm stairs, curriculum on
- Action space: 12 leg joints + waist roll; arms/wrists/neck PD-held
- Symmetry augmentation active
- Episode length ~870/1000, mean knee flexion 36.1 deg, 0.4% of time straight
- Training cost: 3000 iterations, roughly 4-5 h at 1024 envs sharing a GPU with five sibling runs

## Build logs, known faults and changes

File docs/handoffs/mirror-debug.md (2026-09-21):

# MIRROR_DEBUG_HANDOFF — trained policy is broken, suspect mirrored URDF

> In this repository `rl_full.urdf` is [sim/urdf/primo.urdf](../../sim/urdf/primo.urdf) with its meshes in `sim/meshes/` (same file, robot name changed to `primo`).

Written 2026-07-18 on the CAD Mac, for the AI session on the Isaac Sim PC.
User trained a policy on `rl_full.urdf` and it is "super broken" — cause not yet isolated.
This doc hands over the mirroring pipeline plus a concrete debugging plan. Read this before
touching `mirror_urdf.py`.

## What "broken" could mean — narrow it down FIRST

"Broken policy" has causes that have nothing to do with mirroring: reward shaping, PD gains,
episode termination conditions, observation normalization, domain randomization ranges. Before
assuming the URDF, run the four checks below (from `isaac.md`) if you haven't already —
they take minutes and immediately tell you whether the asset is even the right layer to debug.

1. Zero pose: robot stands upright, feet flat, no interpenetration explosion on spawn.
2. Symmetry: command +0.3 rad to BOTH hip rolls -> both legs must swing the SAME way relative
   to the body (both outward, or both inward). Repeat for shoulder rolls.
3. Total articulated mass ~32.2 kg; whole-robot COM at y ~ 0 in zero pose.
4. Knee flexes backward only.

**If test 1 or 2 fails, the URDF is implicated — keep reading.** If all four pass and the robot
holds a commanded static pose correctly but the *trained policy* still fails, the problem is very
likely reward/PD/training-side, not geometry — say so back to the user rather than re-deriving
the mirror math.

## What is verified about the mirror pipeline (don't re-derive from scratch)

`mirror_urdf.py` (repo root, CAD Mac) mirrors a right-side-only Onshape URDF export into a full
robot. This has been checked twice with an independent FK script (not just re-reading the code):

- 30 revolute joints, all 13 left/right pairs at **exactly 0.000 mm** position error and exact
  axis mirror (`aerr` < 1e-6) under the convention below.
- Whole-robot COM y = 0.1 mm in the zero pose.
- Kinematic chain confirmed connected root->pelvis->hip_pitch->...->femur (no hanging subtrees).
- Total mass 32.25 kg, matches BOM-injected component masses.

**Mirror convention** (this is the part most likely to hide a real bug if wrong — verify it
independently on the actual robot before assuming it's fine just because positions match):

- Local origins: `xyz: (x,y,z) -> (x,-y,z)`; `rpy: (r,p,y) -> (-r,p,-y)`.
- Joint axis: `(ax,ay,az) -> (-ax,ay,-az)`.
- Net effect: **the same joint command (same sign) produces mirrored motion on both sides, and
  left/right limits are numerically identical.** This is a DESIGN CHOICE the user asked for
  ("joints of left part should still work as the ones of the right"), not the only valid
  convention. If Isaac Lab, your action-space wrapper, or a reference motion/observation config
  assumes a DIFFERENT convention (e.g. mirrored sign so a positive hip-roll command means
  "adduct" on both sides some other way, or raw URDF axis without any correction), the geometry
  can be perfectly correct while producing a policy that looks broken because commands are being
  interpreted with the wrong sign somewhere in the RL stack. **Check this first** — it is the
  most likely subtle mismatch between a "geometrically correct" URDF and a "trains correctly"
  URDF, and it would NOT be caught by the symmetry check above (which only measures geometry, not
  command semantics).
- Inertials: mass unchanged, COM y flipped, `Ixy`/`Iyz` sign-flipped, `Ixx/Iyy/Izz/Ixz` unchanged.
- Meshes: real vertex-flipped STLs (y flip + triangle winding swap, normals recomputed) — NOT
  negative scale. If you see inside-out geometry or inverted collision normals on the LEFT side
  only, check `mirror_stl()` in the script, but this was visually spot-checked already.

## Known-provisional values (real candidates for "broken" if limits/torques are the issue)

From `mirror_urdf.py`'s `CANON` dict, NOT yet validated against real hardware or careful analysis:

- **All joint velocities** — conservative guesses (10-20 rad/s depending on joint), never derived
  from RobStride datasheets. If the policy wants faster joint speeds than allowed, or the guessed
  caps are unrealistically high for actual actuators, torque/velocity commands could saturate in
  ways that look like "broken" behavior.
- **Ankle pitch/roll effort** (72 / 36 Nm) — provisional estimate of the 2xRS06 differential
  transmission, not a measured or rigorously derived value. Wrong effort here directly breaks
  standing/push-off.
- **Neck limits** (+-1.57 / +-0.70 rad) — guessed, not from any G1 or hardware source.
- **Hip yaw effort** = 36 Nm (RS06, matches current CAD) — this is a KNOWN OPEN QUESTION, not a
  bug: locked BOM wants RS03 (60 Nm) instead. Log hip-yaw torque saturation during turning; if
  it saturates often, that's expected and is a real hardware gate, not a mirroring defect.

## What is explicitly NOT yet done to the URDF (do not assume it's handled)

- No real collision primitives — 15 bodies use full visual meshes copied as collisions
  (convex-decomposed by the importer). Bad collision geometry (foot especially) is a classic
  cause of "policy looks broken / feet clip through ground / robot vibrates".
- Arms/wrists have NO collision geometry at all.
- PD gains, action space, default pose, reward terms are entirely out of scope for this script —
  those live in your Isaac Lab config, not in the URDF.

## Suggested debugging order

1. Run the 4 acceptance tests above if not already done. Report exact pass/fail per test.
2. If symmetry test (test 2) fails in Isaac even though the offline FK check on the CAD Mac
   passed: the discrepancy is almost certainly in how Isaac Lab's action wrapper maps policy
   outputs to joint commands for left vs right (see "mirror convention" above), not in the URDF
   file itself. Compare your action-to-joint mapping code against the convention stated above.
3. If test 1 fails (doesn't stand / explodes on spawn): check PD gains are set on EVERY joint
   (a joint with no drive config is passive and will flop — this was flagged in the earlier
   handoff for the neck) and check foot collision geometry / initial penetration.
4. If it stands under a scripted PD pose but the TRAINED policy is broken: this is almost
   certainly reward/observation/action-space/domain-randomization, not the URDF. Do not keep
   pulling on the mirror thread — report back what specifically breaks (falls immediately? one
   leg drags? oscillates? asymmetric gait despite symmetric reward?) so the CAD Mac side can help
   target the fix instead of re-auditing geometry that has already passed independent checks.

## Files you need

- `mirror_urdf.py` — the generator, repo root on the CAD Mac (also viewable there; ask the user
  to paste it or `cat` it into this session if you need the source directly).
- `~/Downloads/rl_full/urdf/rl_full.urdf` + `~/Downloads/rl_full/meshes/` — the last verified
  build (2026-07-18 12:06, 32.25 kg, symmetry OK). If this is not what was imported into Isaac,
  get the exact file that was actually used for training first — a stale or hand-edited copy
  would explain everything without any bug in the pipeline.
- `isaac.md` — general import/PD/acceptance-test guidance, written same day.

## Report back

Once isolated, report to the CAD Mac session (via the user) with: which of the 4 tests failed,
and if it's a genuine geometry/mirror bug, the specific joint/link name and the numeric
discrepancy (not just "it's mirrored wrong") so it can be fixed once in `mirror_urdf.py` and
re-verified with the same FK script rather than patched by hand in the URDF.

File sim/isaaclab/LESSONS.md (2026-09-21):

# Traps and lessons

Each entry is symptom, cause, fix. These cost hours individually. Most are not specific to this
robot — the Isaac Lab ones apply to any humanoid locomotion project.

---

## A. Reward design

### A1. A locked-knee gait is what your reward set is quietly asking for
**Symptom** — the robot walks on straight, stiff legs. Looks wrong, survives fine.
**Cause** — a locked knee carries body load through structure at near-zero torque. A flexed knee
pays `dof_torques_l2` every step. If nothing in the reward *asks* for flexion, locking is optimal.
**Fix** — an explicit penalty on straightness, strong enough to matter:
`knee_straightness(min_bend=0.25)` at weight -2.0. Measured effect: 96% of time straight becomes
0.4%. A weak version (-0.5, min 0.15) does literally nothing.
**Generalises to** — any posture you assume will "emerge". If it costs torque and earns nothing,
it will not emerge.

### A2. Constraining the symptom is not changing the incentive
**Symptom** — capping pelvis height to force a crouch had no effect on knee angle (94.5% straight).
**Cause** — the robot satisfied the height cap by other means (ankle/hip posture) while keeping the
knees locked.
**Fix** — penalise the quantity you actually care about.

### A3. New penalties belong at nudge strength, not constraint strength
**Symptom** — added several gait-quality penalties at once; all six variants plateaued at ~65
episode length and looked like broken recipes.
**Cause** — combined penalty magnitude suppressed early exploration. The policy could not find any
behaviour that scored well, so it found none.
**Fix** — halve everything (about -0.3 to -1.0 for shaping terms). Five of six then reached 555-859.

### A4. Episode length measures not-falling, not gait quality
**Symptom** — 983/1000 episode length and 0.03 velocity error, with a visibly lame gait.
**Fix** — judge gait on video and on measured joint angles. Survival metrics saturate long before
quality does, and past that point they cannot rank recipes at all.

### A5. Rewarding long air time rewards hopping
**Symptom** — raising the air-time threshold for longer steps produced jumping.
**Cause** — air-time reward pays for *being airborne*; a two-foot hop maximises it.
**Fix** — pair it with `no_jumps` (`mdp.desired_contacts`, penalising timesteps where no foot is in
contact) so the air time must come from one foot at a time.

### A6. The fixed periodic gait clock does not work on this morphology
**Symptom** — four separate attempts (TienKung-style 0.85 s swing/stance clock) all failed:
episode length ~90 while siblings reached 555-859.
**Cause** — a rigid timing schedule over-constrains once combined with any other gait shaping.
**Fix** — do not use it here. Alternating gait emerges from `feet_air_time` + `no_jumps` alone.

### A7. Bipeds get no symmetry help from Isaac Lab, and they benefit from it
**Symptom** — persistent asymmetric limp that survived reward retuning and terrain fine-tuning.
**Cause** — no official Isaac Lab biped config (H1, G1, Cassie, Digit) uses symmetry augmentation.
Only ANYmal, a quadruped, does.
**Fix** — `code/symmetry/humanoid_biped.py`, wired via `RslRlSymmetryCfg(use_data_augmentation=True)`.
Reached the same episode length in ~1/3 the iterations and visibly reduced the limp. Because this
URDF mirrors the joint axes, mirroring is a plain left-right swap with **no per-joint sign flips**
(ANYmal needs them). Base-frame quantities still flip: lin_vel y, ang_vel x and z, gravity y,
command vy and wz, and the height-scan grid.
**Verify it is actually running** — `verify_symmetry.py`. The augmentation has dimension-mismatch
fallbacks that silently no-op, which would look identical to "symmetry did not help".

### A8. Fine-tuning cannot restructure an entrenched gait
**Symptom** — 500 iterations of rough-terrain fine-tuning on a lame flat policy: still lame.
**Fix** — retrain from scratch when the *shape* of the behaviour is wrong. Fine-tune only for
adaptation (new terrain, new speeds), not correction.

---

## B. Isaac Lab API traps

### B1. `base_height` termination is flat-terrain-only — it silently kills rough training
**Symptom** — every rough-terrain run pinned at 1-8 episode length while the same policy scored
983 on flat.
**Cause** — `mdp.root_height_below_minimum` compares against **absolute world z**. Its own docstring
says "currently only supported for flat terrains". On generated terrain, a robot spawned in a pit or
on descending stairs is already below threshold at t=0 and terminates on frame one.
**Fix** — `self.terminations.base_height = None` in any rough config. Keep it on flat, where it is a
useful fall detector.
**How to catch this class of bug fast** — read `Episode_Termination/*` in the log before changing
anything. It names the killer directly.

### B2. Joints outside the action space are NOT held at your configured pose
**Symptom** — arms configured along the body kept appearing in the CAD forward pose in every video,
across many runs.
**Cause** — action terms write PD targets only for joints in the action space. Joints outside it
never get a target, so their drives pull toward **zero** — which is the URDF zero pose, not your
`init_state.joint_pos`. `init_state` sets the spawn *state* and the action offset, not the held
*target*. Isaac Lab's `reset_scene_to_default` has an opt-in `reset_joint_targets` flag that
acknowledges exactly this.
**Fix** — `code/tasks/events.py`: a reset-mode event writing default targets for **all** joints.
**Verify** — extract a frame from the actual training/play video, do not trust a standalone preview
script (a preview loop that writes all targets every step will always look correct).

### B3. Flat and rough have different observation sizes
**Symptom** — a flat checkpoint will not load into a rough task.
**Cause** — rough adds a 187-dim height scan (grid 0.1 m resolution, 1.6 x 1.0 m).
**Fix** — for flat-to-rough transfer, disable the height scanner (blind rough-terrain locomotion)
so the observation vector matches.

### B4. `play.py` and `train.py` take checkpoints differently
`play.py --checkpoint` wants a **full path**. `train.py` wants `--load_run <dir> --checkpoint
<filename>`, and `--resume` is a flag (`--resume True` is a parse error). `train.py --resume` also
searches inside the *new* experiment directory, so seed it with the source checkpoint first.

### B5. Straight legs at zero are a singular pose
Legs at all-zeros have no knee moment arm and buckle under load. Use a slight crouch as the default
(G1 neutral: hip pitch -0.20, knee 0.42, ankle pitch -0.23).
**But note** — a humanoid is not expected to stand passively with fixed PD gains. A "does it stand
still?" test returning FALLS is **not** a valid asset gate; real humanoids need active balance.
Do not conclude the asset is broken from that test (this was concluded once, wrongly).

---

## C. Asset and collision

### C1. Foot collision: use the sole plate, not the mesh bounding box
**Symptom (first attempt, wrong)** — replaced the foot mesh with a box built from the full-mesh AABB:
48.9 mm tall and 81.5 mm wide.
**Why wrong** — the true load-bearing sole plate is 199.9 x 70.0 x **11.9** mm. The 81.5 mm came from
the ankle *bracket*, not the sole, giving a **16% oversized support polygon** — a policy flattered in
sim that would not transfer. The 48.9 mm height made a brick whose vertical faces catch stair edges
the real thin plate clears.
**Fix** — measure the sole band specifically (lowest ~12 mm of the mesh) and box that.
`simplify_foot_collision.py` and `audit_collisions.py` do this and report box-vs-mesh fidelity.

### C2. Full-mesh collision on packed assemblies jitters under self-collision
The ankle gimbal cluster (screws, cranks, joint block) as raw convex-decomposed meshes overlaps at
rest and vibrates. With self-collision **off** (the training default) it is harmless. Simplify those
volumes before ever enabling self-collision.

### C3. Verify the URDF mirror with FK before blaming geometry
`foot_zero_check.py` walks the kinematic chain: rotation root to both feet at zero pose should be
exactly identity and symmetric. It was, here — which correctly ruled out the mirror pipeline early
and saved a lot of wasted geometry debugging.

---

## D. Tooling and workflow

### D1. Measure the thing you are judging
Two full rounds were spent tuning step size while the knees were locked and nobody had measured a
joint angle. `knee_probe.py` (patches `play.py`'s `env.step` to sample joint state during a rollout)
turns "do the knees bend?" into a number in ~3 minutes. Build the probe before the third argument
about what a video shows.
Implementation note: rebuilding the RSL-RL runner by hand fails on nested `class_name` keys — patch
the stock `play.py` instead, and insert the script directory on `sys.path` (it imports `cli_args`).

### D2. `PYTHONUNBUFFERED=1`, always
Redirected Python output is buffered. Without this, diagnostics vanish and a working process looks
hung.

### D3. Unique log file per launch
Reusing a log path while a previous process tears down causes a file-sharing violation that
silently wedges the new process. This was misdiagnosed for a long time as "two Isaac instances kill
each other". They do not — several coexist fine.

### D4. Launch runs sequentially, not on a fixed stagger
Isaac takes about 90 s to boot. Six launches 12 s apart all crashed ("Failed to set root link
transforms"). Even a 90 s fixed stagger wedged 4 of 6 once. The reliable pattern: launch one,
**wait for its first `Learning iteration` line**, then launch the next
(`launch_sequential.ps1`). Add a load gate between batches and a health watchdog during training.

### D5. ffmpeg finishes writing asynchronously
Copying the mp4 immediately after `play.py` returns yields a truncated file that renders as an
empty scene. Poll the file size until stable before copying. This produced a full round of
"there are no robots in the video".

### D6. The Play camera does not follow the robot by default
On rough terrain the robots spawn across a large tile grid and walk out of frame, so the video looks
empty. Set `viewer.origin_type = "asset_root"`, `viewer.asset_name = "robot"`. Note `viewer.eye` and
`viewer.lookat` are **offsets from the robot root** (pelvis, ~0.78 m up), not world coordinates —
`lookat` z must be negative to see the feet. Keep the eye high or the camera clips through stair
geometry and produces black frames.

### D7. Do not change five variables at once
Stated plainly because it was violated repeatedly and cost the most time overall. When a result is
bad, change one thing. Keep an unchanged control run in every batch — it is what tells you whether
the baseline still reproduces.

### D8. Distinguish a slow start from a broken recipe by the right reference
Recipes with heavy penalties legitimately start slow. G1/H1/Cassie hit ~900 by iteration 340;
Hybrid started at 178 and only recovered to 850 by iteration 700 — and Digit went 66 to 828. Judge
against the *slow* reference curve and give a run until iteration ~500-600 before killing it. Two
good runs were nearly killed on early evidence.

---

## E. Machine and environment

- **NVIDIA driver 580.88** for Isaac Sim 5.1 on Blackwell. 595.x crashes the renderer. Pin it.
- **tensordict 0.8.3**. 0.13 crashes inside Kit with torch 2.7.
- **Do not stack a VLA training run on top of six RL runs** — the machine hard-reset. Six RL runs
  alone at 1024 envs use only ~26 GB GPU, 126 W, 63 C. Coordinate heavy workloads.
- Headless rendering is far more reliable than the interactive GUI on this setup. When the GUI
  stalls, render a video instead of fighting it.

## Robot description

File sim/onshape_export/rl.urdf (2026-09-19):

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
<robot name="rl">
    <link name="2026_06_26_21_13_20_0957">
        <inertial>
            <mass value="1.29723e-06" />
            <origin xyz="0.04775 -0.17345 -0.545296" rpy="0 -0 0" />
            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
        </inertial>
        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
    </link>
    <link name="2026_06_26_21_13_20_0957__2_">
        <inertial>
            <mass value="1e-09" />
            <origin xyz="0 0 0" rpy="0 -0 0" />
            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
        </inertial>
    </link>
    <link name="2026_06_26_21_13_20_0957__3_">
        <inertial>
            <mass value="1e-09" />
            <origin xyz="0 0 0" rpy="0 -0 0" />
            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
        </inertial>
    </link>
    <link name="2026_06_26_21_13_20_0957__4_">
        <inertial>
            <mass value="1e-09" />
            <origin xyz="0 0 0" rpy="0 -0 0" />
            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
        </inertial>
    </link>
    <link name="d435i_solid__1_">
        <inertial>
            <mass value="7.95245e-08" />
            <origin xyz="0.000632972 -4.0428e-18 -6.7e-05" rpy="0 -0 0" />
            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
        </inertial>
        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
    </link>
    <link name="mate_connector_1">
        <inertial>
            <mass value="1e-09" />
            <origin xyz="0 0 0" rpy="0 -0 0" />
            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
        </inertial>
    </link>
    <link name="mate_connector_10">
        <inertial>
            <mass value="1e-09" />
            <origin xyz="0 0 0" rpy="0 -0 0" />
            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
        </inertial>
    </link>
    <link name="mate_connector_11">
        <inertial>
            <mass value="1e-09" />
            <origin xyz="0 0 0" rpy="0 -0 0" />
            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
        </inertial>
    </link>
    <link name="mate_connector_12">
        <inertial>
            <mass value="1e-09" />
            <origin xyz="0 0 0" rpy="0 -0 0" />
            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
        </inertial>
    </link>
    <link name="mate_connector_13">
        <inertial>
            <mass value="1e-09" />
            <origin xyz="0 0 0" rpy="0 -0 0" />
            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
        </inertial>
    </link>
    <link name="mate_connector_14">
        <inertial>
            <mass value="1e-09" />
            <origin xyz="0 0 0" rpy="0 -0 0" />
            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
        </inertial>
    </link>
    <link name="mate_connector_15">
        <inertial>
            <mass value="1e-09" />
            <origin xyz="0 0 0" rpy="0 -0 0" />
            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
        </inertial>
    </link>
    <link name="mate_connector_16">
        <inertial>
            <mass value="1e-09" />
            <origin xyz="0 0 0" rpy="0 -0 0" />
            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
        </inertial>
    </link>
    <link name="mate_connector_17">
        <inertial>
            <mass value="1e-09" />
            <origin xyz="0 0 0" rpy="0 -0 0" />
            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
        </inertial>
    </link>
    <link name="mate_connector_18">
        <inertial>
            <mass value="1e-09" />
            <origin xyz="0 0 0" rpy="0 -0 0" />
            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
        </inertial>
    </link>
    <link name="mate_connector_19">
        <inertial>
            <mass value="1e-09" />
            <origin xyz="0 0 0" rpy="0 -0 0" />
            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
        </inertial>
    </link>
    <link name="mate_connector_2">
        <inertial>
            <mass value="1e-09" />
            <origin xyz="0 0 0" rpy="0 -0 0" />
            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
        </inertial>
    </link>
    <link name="mate_connector_20">
        <inertial>
            <mass value="1e-09" />
            <origin xyz="0 0 0" rpy="0 -0 0" />
            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
        </inertial>
    </link>
    <link name="mate_connector_3">
        <inertial>
            <mass value="1e-09" />
            <origin xyz="0 0 0" rpy="0 -0 0" />
            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
        </inertial>
    </link>
    <link name="mate_connector_4">
        <inertial>
            <mass value="1e-09" />
            <origin xyz="0 0 0" rpy="0 -0 0" />
            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
        </inertial>
    </link>
    <link name="mate_connector_5">
        <inertial>
            <mass value="1e-09" />
            <origin xyz="0 0 0" rpy="0 -0 0" />
            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
        </inertial>
    </link>
    <link name="mate_connector_6">
        <inertial>
            <mass value="1e-09" />
            <origin xyz="0 0 0" rpy="0 -0 0" />
            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
        </inertial>
    </link>
    <link name="mate_connector_7">
        <inertial>
            <mass value="1e-09" />
            <origin xyz="0 0 0" rpy="0 -0 0" />
            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
        </inertial>
    </link>
    <link name="mate_connector_8">
        <inertial>
            <mass value="1e-09" />
            <origin xyz="0 0 0" rpy="0 -0 0" />
            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
        </inertial>
    </link>
    <link name="mate_connector_9">
        <inertial>
            <mass value="1e-09" />
            <origin xyz="0 0 0" rpy="0 -0 0" />
            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
        </inertial>
    </link>
    <link name="part_10_rs06">
        <inertial>
            <mass value="0.000264538" />
            <origin xyz="5.19845e-19 -0.133993 -0.647296" rpy="0 -0 0" />
            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
        </inertial>
        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
    </link>
    <link name="part_11_rs06">
        <inertial>
            <mass value="0.000264538" />
            <origin xyz="5.19845e-19 -0.119407 -0.545296" rpy="0 -0 0" />
            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
        </inertial>
        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
    </link>
    <link name="part_12_rs06">
        <inertial>
            <mass value="0.000264538" />
            <origin xyz="5.2649e-19 -0.0766671 0.29178" rpy="0 -0 0" />
            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
        </inertial>
        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
    </link>
    <link name="part_13_rs06">
        <inertial>
            <mass value="0.000264538" />
            <origin xyz="-0.0120429 -0.15621 0.29178" rpy="0 -0 0" />
            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
        </inertial>
        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
    </link>
    <link name="part_14_rs06">
        <inertial>
            <mass value="0.000264538" />
            <origin xyz="5.19845e-19 -0.152667 0.105243" rpy="0 -0 0" />
            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
        </inertial>
        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
    </link>
    <link name="part_15_rs03">
        <inertial>
            <mass value="0.000429666" />
            <origin xyz="-0.0263845 -7.31928e-22 -2.67306e-18" rpy="0 -0 0" />
            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
        </inertial>
        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
    </link>
    <link name="part_16_rs05">
        <inertial>
            <mass value="7.26619e-05" />
            <origin xyz="1.423e-21 0.00212394 0.37978" rpy="0 -0 0" />
            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
        </inertial>
        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
    </link>
    <link name="part_17_rs05">
        <inertial>
            <mass value="7.26619e-05" />
            <origin xyz="1.423e-21 -3.03916e-19 0.315656" rpy="0 -0 0" />
            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
        </inertial>
        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
    </link>
    <link name="part_18_tibia">
        <inertial>
            <mass value="0.356912" />
            <origin xyz="-9.9581e-18 0.000714559 -0.152469" rpy="0 -0 0" />
            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
        </inertial>
        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
    </link>
    <link name="part_19_shoulder_screw_long">
        <inertial>
            <mass value="0.0677945" />
            <origin xyz="-1.26245e-35 -0.131672 -0.739306" rpy="0 -0 0" />
            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
        </inertial>
        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
    </link>
    <link name="part_1_rs04">
        <inertial>
            <mass value="0.000528095" />
            <origin xyz="1.37839e-19 -0.105442 -0.439296" rpy="0 -0 0" />
            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
        </inertial>
        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
    </link>
    <link name="part_20_shoulder_screw_long">
        <inertial>
            <mass value="0.0677945" />
            <origin xyz="-0.0237779 -1.94289e-16 0" rpy="0 -0 0" />
            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
        </inertial>
        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
    </link>
    <link name="part_21_ankle_joint">
        <inertial>
            <mass value="0.0195313" />
            <origin xyz="7.54444e-16 -0.03 -0.0068128" rpy="0 -0 0" />
            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
        </inertial>
        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
    </link>
    <link name="part_22_foot">
        <inertial>
            <mass value="0.225673" />
            <origin xyz="0.0285253 -0.1267 -0.77829" rpy="0 -0 0" />
            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
        </inertial>
        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
    </link>
    <link name="part_23_upper_motor_ankle_crank">
        <inertial>
            <mass value="0.0616906" />
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

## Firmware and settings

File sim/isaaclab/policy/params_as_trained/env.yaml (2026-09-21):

viewer:
  eye: !!python/tuple
  - 7.5
  - 7.5
  - 7.5
  lookat: !!python/tuple
  - 0.0
  - 0.0
  - 0.0
  cam_prim_path: /OmniverseKit_Persp
  resolution: !!python/tuple
  - 1280
  - 720
  origin_type: world
  env_index: 0
  asset_name: null
  body_name: null
sim:
  physics_prim_path: /physicsScene
  device: cuda:0
  dt: 0.005
  render_interval: 4
  gravity: !!python/tuple
  - 0.0
  - 0.0
  - -9.81
  enable_scene_query_support: false
  use_fabric: true
  physx:
    solver_type: 1
    solve_articulation_contact_last: false
    min_position_iteration_count: 1
    max_position_iteration_count: 255
    min_velocity_iteration_count: 0
    max_velocity_iteration_count: 255
    enable_ccd: false
    enable_stabilization: false
    enable_external_forces_every_iteration: false
    enable_enhanced_determinism: false
    bounce_threshold_velocity: 0.5
    friction_offset_threshold: 0.04
    friction_correlation_distance: 0.025
    gpu_max_rigid_contact_count: 8388608
    gpu_max_rigid_patch_count: 327680
    gpu_found_lost_pairs_capacity: 2097152
    gpu_found_lost_aggregate_pairs_capacity: 33554432
    gpu_total_aggregate_pairs_capacity: 2097152
    gpu_collision_stack_size: 67108864
    gpu_heap_capacity: 67108864
    gpu_temp_buffer_capacity: 16777216
    gpu_max_num_partitions: 8
    gpu_max_soft_body_contacts: 1048576
    gpu_max_particle_contacts: 1048576
  physics_material:
    func: isaaclab.sim.spawners.materials.physics_materials:spawn_rigid_body_material
    static_friction: 1.0
    dynamic_friction: 1.0
    restitution: 0.0
    friction_combine_mode: multiply
    restitution_combine_mode: multiply
    compliant_contact_stiffness: 0.0
    compliant_contact_damping: 0.0
  render:
    enable_translucency: null
    enable_reflections: null
    enable_global_illumination: null
    antialiasing_mode: null
    enable_dlssg: null
    enable_dl_denoiser: null
    dlss_mode: null
    enable_direct_lighting: null
    samples_per_pixel: null
    enable_shadows: null
    enable_ambient_occlusion: null
    dome_light_upper_lower_strategy: null
    carb_settings: null
    rendering_mode: null
  create_stage_in_memory: false
  logging_level: WARNING
  save_logs_to_file: true
  log_dir: null
ui_window_class_type: isaaclab.envs.ui.manager_based_rl_env_window:ManagerBasedRLEnvWindow
seed: 42
decimation: 4
scene:
  num_envs: 1024
  env_spacing: 2.5
  lazy_sensor_update: true
  replicate_physics: true
  filter_collisions: true
  clone_in_fabric: false
  robot:
    class_type: isaaclab.assets.articulation.articulation:Articulation
    prim_path: /World/envs/env_.*/Robot
    spawn:
      func: isaaclab.sim.spawners.from_files.from_files:spawn_from_usd
      visible: true
      semantic_tags: null
      copy_from_source: true
      mass_props: null
      deformable_props: null
      rigid_props:
        rigid_body_enabled: null
        kinematic_enabled: null
        disable_gravity: false
        linear_damping: 0.0
        angular_damping: 0.0
        max_linear_velocity: 1000.0
        max_angular_velocity: 1000.0
        max_depenetration_velocity: 1.0
        max_contact_impulse: null
        enable_gyroscopic_forces: null
        retain_accelerations: false
        solver_position_iteration_count: null
        solver_velocity_iteration_count: null
        sleep_threshold: null
        stabilization_threshold: null
      collision_props: null
      activate_contact_sensors: true
      scale: null
      articulation_props:
        articulation_enabled: null
        enabled_self_collisions: false
        solver_position_iteration_count: 8
        solver_velocity_iteration_count: 4
        sleep_threshold: null
        stabilization_threshold: null
        fix_root_link: null
      fixed_tendons_props: null
      spatial_tendons_props: null
      joint_drive_props: null
      visual_material_path: material
      visual_material: null
      usd_path: C:/Users/WKS/Documents/humanoid/rl_full_isaac/usd/rl_full.usd
      variants: null
    init_state:
      pos: !!python/tuple
      - 0.0
      - 0.0
      - 0.797
      rot: !!python/tuple
      - 1.0
      - 0.0
      - 0.0
      - 0.0
      lin_vel: !!python/tuple
      - 0.0
      - 0.0
      - 0.0
      ang_vel: !!python/tuple
      - 0.0
      - 0.0
      - 0.0
      joint_pos:
        .*_hip_pitch_joint: -0.2
        .*_knee_joint: 0.42
        .*_ankle_pitch_joint: -0.23
        .*_shoulder_pitch_joint: 0.0
        .*_shoulder_roll_joint: 0.2617993877991494
        .*_elbow_joint: 1.5707963267948966
      joint_vel:
        .*: 0.0
    collision_group: 0
    debug_vis: false
    articulation_root_prim_path: null
    soft_joint_pos_limit_factor: 0.9
    actuators:
      legs:
        class_type: isaaclab.actuators.actuator_pd:ImplicitActuator
        joint_names_expr:
        - .*_hip_pitch_joint
        - .*_hip_roll_joint
        - .*_knee_joint
        effort_limit: null
        velocity_limit: null
        effort_limit_sim: 120.0
        velocity_limit_sim: 10.0
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

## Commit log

2026-09-19 umanoide: first public release package (design in progress)
    [ankle-gimbal.3mf, bom.csv, bom.xlsx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]
2026-09-19 Add CAD tour video link
2026-09-19 Add platform links: Printables, Thingiverse, MakerWorld
2026-09-19 MakerWorld status: resubmit with a real print photo
2026-09-19 Rename to primo; printable STL, URDF with meshes, AGENTS.md entry point, 4K video
    [Part_10_rs06.stl, Part_10_rs06_mirror.stl, Part_11_rs06.stl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]
2026-09-19 Creality and MakerWorld wait for real print photos
2026-09-21 Add locomotion training package and motor selection
    sim/isaaclab: trained walking policy, Isaac Lab task code, diagnostic scripts, handoff, lessons, results, next steps, setup.
    docs/motor-selection.md: why RobStride, comparison with Encos (Asimov), CubeMars and others.
    actuator-tables: superseded choices marked, wrong CubeMars sizes struck.
    [env.yaml]
2026-09-21 English only; neutral wording for AI assistance; BOM candidate rows in English
    [bom.xlsx]
2026-09-21 Generated bones pilot (cad/bonegen) and actuator integration notes
    [final.stl]

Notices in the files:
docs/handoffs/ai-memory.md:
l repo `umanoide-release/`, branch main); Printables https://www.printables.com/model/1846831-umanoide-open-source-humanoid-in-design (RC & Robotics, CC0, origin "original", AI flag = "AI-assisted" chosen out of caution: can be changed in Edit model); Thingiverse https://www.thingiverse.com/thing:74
